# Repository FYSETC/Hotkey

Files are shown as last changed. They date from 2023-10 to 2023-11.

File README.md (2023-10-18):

# Hotkey

## Introduction
Elevate your 3D printing experience with our latest innovation, the HotKey Macro Buttons designed exclusively for the discerning 3D printing enthusiast.

**Key Features:**
- Dedicated MCU: Built on the robust and reliable RP2040 platform, our HotKey system guarantees a seamless integration and flawless performance.
- 12 Linear Red Switched Macro Buttons: Customize your 3D printer like never before. With 12 programmable macro buttons, execute your frequently used commands with a single press. Whether you’re toggling between settings, setting up a new print, or any other task, speed and convenience are at your fingertips.
- Designed with Voron in Mind: While our HotKey Macro Buttons can enhance any 3D printing setup, they were meticulously designed with the Voron Trident and Voron 2.4 models as the primary inspiration. This ensures an impeccable fit and intuitive usage for Voron users.
- Seamless Integration: Add these buttons to your printer's skirt without any hassle. Our design philosophy prioritizes both aesthetics and functionality, ensuring your 3D printer not only gets a boost in efficiency but also looks sleeker.

## Firmware
### Katapult (Formally CAN Boot)
Katapult is used to allow easy upgrading of your formware down the line, and is not just soley for CAN based devices. 
#### Setup Katapult
If you already have Katapult installed, you can skip this step. 

1. Connect to your Klipper host computer via ssh.
2. Clone the Katapult firmware to your Klipper Host
```bash
cd ~/
git clone https://github.com/Arksine/katapult
```
3. Within either Fluidd or Mainsail UI, Edit your Moonraker.conf and add the following at the bottom to allow Moonraker to manage your Katapult updates. 
```yaml
[update_manager Katapult]
type: git_repo
path: ~/katapult
origin: https://github.com/Arksine/katapult.git
is_system_service: False
```
#### Compile Katapult Firmware
1. Navigate into the Katapult Directory
```bash
cd ~/katapult
```
2. Run make clean 
```bash
make clean KCONFIG_CONFIG=config.hotkey
```
3. Open menuconfig 
```bash
make menuconfig KCONFIG_CONFIG=config.hotkey
```
4. Set the following settings
    - Micro-controller Architecture (Raspberry Pi RP2040)
    - Flash Chip (W25Q080 with CLKDIV 2)
    - Build Katapult deployment application (Do not build)
    - Communication interface (USB)
    - () GPIO pins to set on bootloader entry
    - [*] Support bootloader entry on rapid double clip of reset button
    - [_] Enable bootloader entry on button (or gpio) state
    - [_] Enable Status LED
  


5. Quit and save the configuration
6. Run the make command to compile the firmware
```bash
   make KCONFIG_CONFIG=config.hotkey -j4
```
7. You should now have a katapult.uf2 file at ~/katapult/out/

#### Burn Katapult Firmware to the Hotkey Pad
1. Use a USB-C data cable to connect the Hotkey Pad board to the klipper host.
2. Press the boot button while inserting the USB Cable to put the Hotkey Pad into boot mode.
3. Run lsusb to see if the connection is successful.
```bash
  lsusb
```


You should see a device with the ID `2e8a:0003 Raspberry Pi RP2 Boot`, if that doesn't show, please start at step 1 again. 

4. Flash the Hotkey Pad
```bash
sudo make KCONFIG_CONFIG=config.hotkey flash FLASH_DEVICE=2e8a:0003
```
- You will be prompted to enter your password.
- This will flash the Katapult bootloader image and restart the Hotkey Pad
5. Once complete, reboot your host computer and move onto flashing Klipper

### Klipper

#### Compile Klipper firmware for the Hotkey Pad
1. Connect to your Klipper host computer via ssh. 
2. cd to the Klipper directory 
```bash
cd ~/klipper
```
3. Run make clean 
```bash
make clean KCONFIG_CONFIG=config.hotkey
```
4. Open menuconfig 
```bash
make menuconfig KCONFIG_CONFIG=config.hotkey
```
5. Set the following settings
    - [*] Enable extra low-level configuration options
    - Micro-controller Architecture (Raspberry Pi RP2040)
    - Bootloader offset (16KiB bootloader)
    - Communication interface (USB)
    - ( ) GPIO pins to set at micro-controller startup (NEW)


6. Quit (press q) and save the configuration
7. Run Make to compile the firmware
```bash
make KCONFIG_CONFIG=config.hotkey -j4
```
#### Flash Klipper USB firmware with Katapult over USB
1. Find the Serial ID (hint - it will likely say rp2040 in the name. If you have multiple rp2040 based devices, check your printer.cfg and see which ones you are already using).
```bash
ls /dev/serial/by-id
```


2. Copy the ID containing ‘rp2040’ and make a note of it for use in your printer.cfg.
3. Run the make flash command to flash the firmware
```bash
make KCONFIG_CONFIG=config.hotkey flash FLASH_DEVICE= {Your serial ID here }
```
   **Example**
```bash
make KCONFIG_CONFIG=config.hotkey flash FLASH_DEVICE=/dev/serial/by-id/usb-katapult_rp2040_E6625C4893378533-if00
```


 4. Your Hotkey Pad should now have Klipper Firmware installed and be ready to use. You can check it's worked by running another
```bash
ls /dev/serial/by-id
```

## Configuration 

### How to use all this stuff:
1.  Copy this .cfg file into your Klipper config directory and then add `[include Hotkey.cfg]` to the top of your printer.cfg in order to register the MCU, LEDs and macros with Klipper.
2.  If you installed the Stealthburner as well and want to get the "STATUS_ERROR" state transmitted to the hotkey button PCB, you have to replace the "STATUS_ERROR" Macro in your stealthburner_leds.cfg with this:
```bash
[gcode_macro status_error]
gcode:
    STATUS_ERROR_HOTKEY
    _set_sb_leds_by_name leds="logo" color="error" transmit=0
    _set_sb_leds_by_name leds="nozzle" color="error" transmit=1
```
3.  Connect the PCB via USB to your RaspberryPi and SSH to your Pi
4.  Get the Serial ID of the PCB with "ls /dev/serial/by-id/*". Usualy it´s like usb-Klipper_rp2040_xxx
5.  Replace the serial under the [mcu hotkey] section with your id
6.  Save your config and restart Klipper.

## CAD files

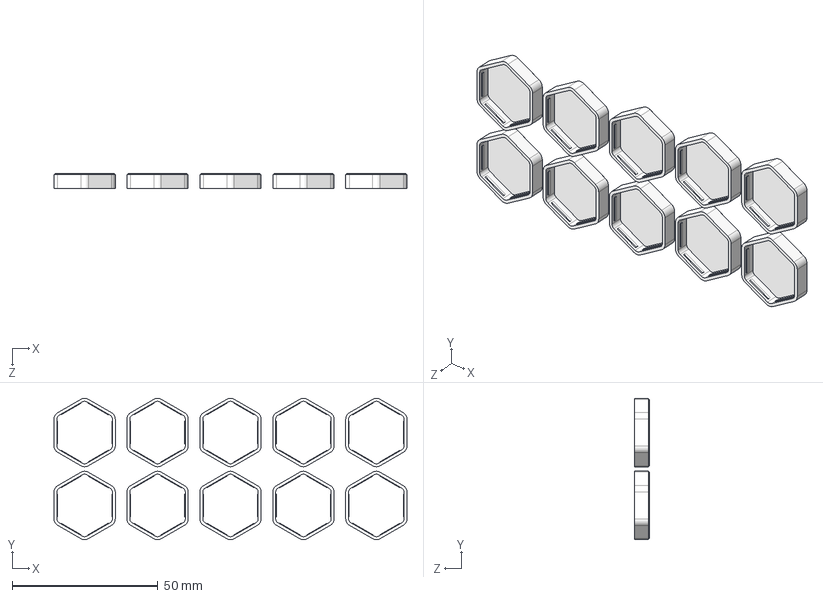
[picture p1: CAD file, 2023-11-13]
Models and dimensions/Button_Caps/KBB.STEP
121.0 x 48.5 x 5.10 mm

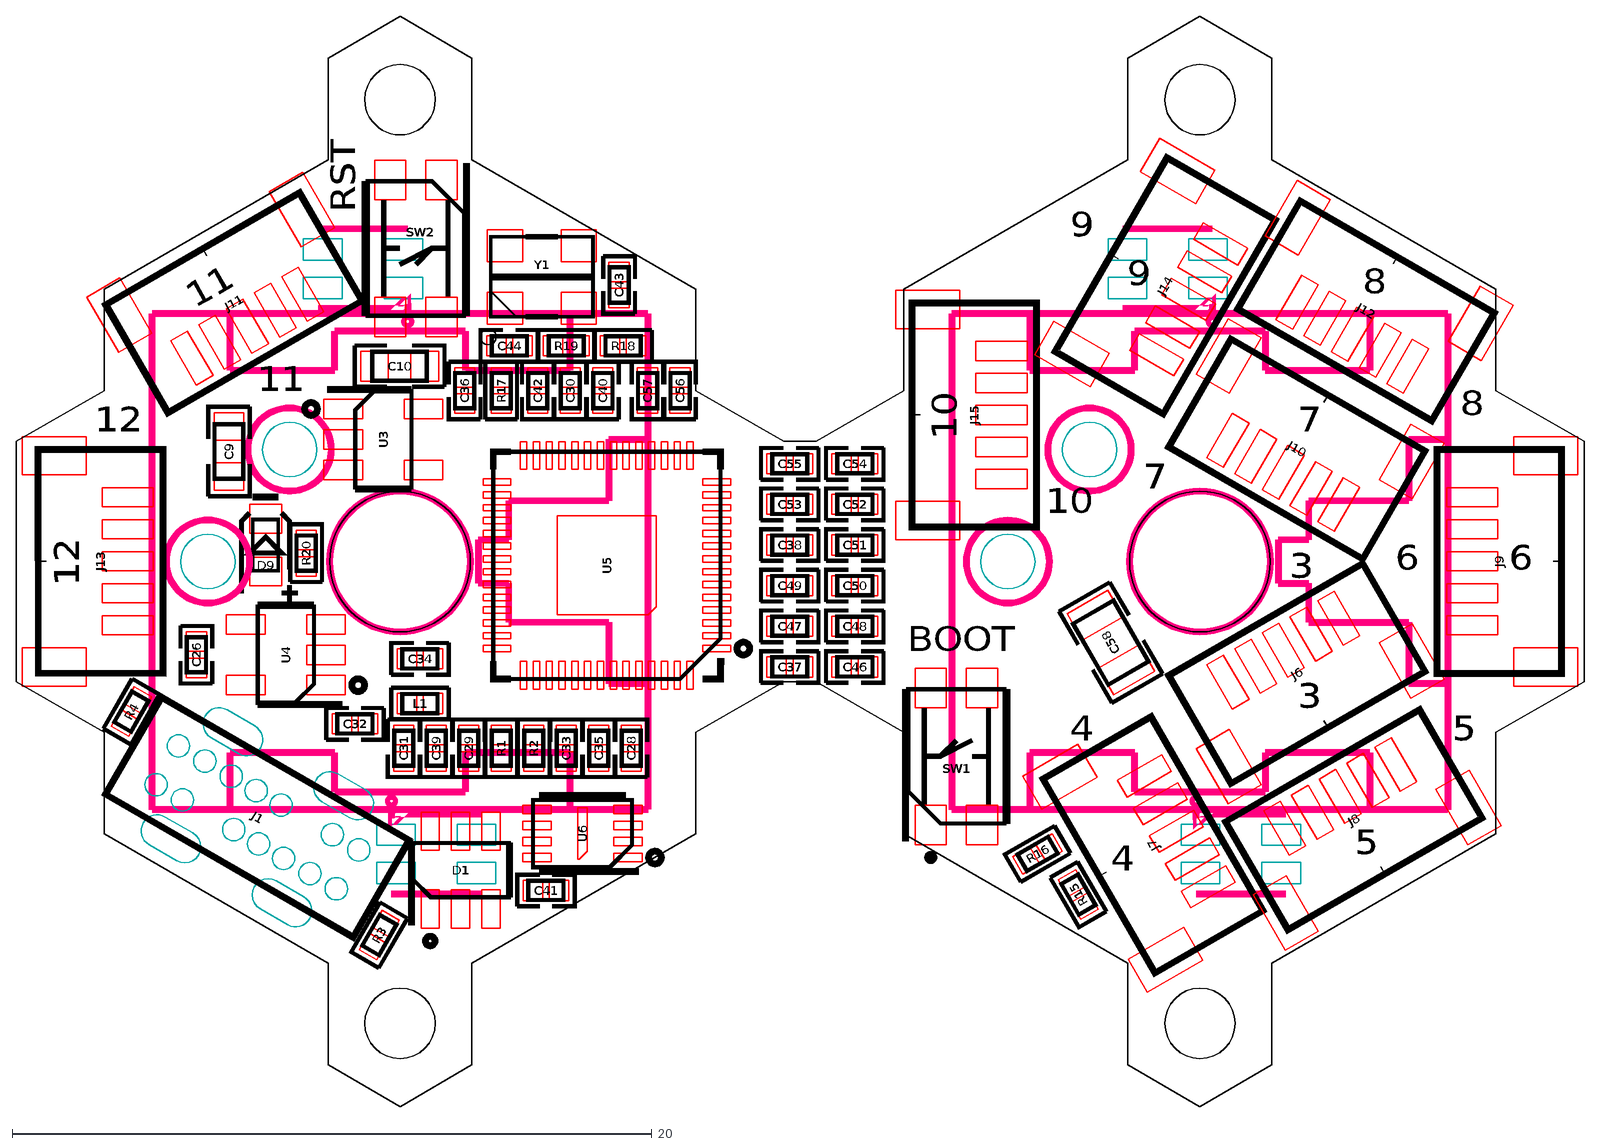
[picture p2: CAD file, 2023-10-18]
Models and dimensions/SKIRT_BUTTON_A2_CAD.dxf
D9
J1
C58
U6
J15
J14
J13
J12
J11
J10
J6
J7
J8
J9
U5
SW2
SW1
C10
C9
R20
L1
R18
R19
R4
R3
R16
R17
R15
R2
R1
C57
C56
C55
C54
C53
C52
C51
C50
C49
C48
C47
C46
C37
C42
C41
C40
C39
C38
C36
C43
C35
C32
C33
C34
C44
C31
C26
C30
C29
C28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

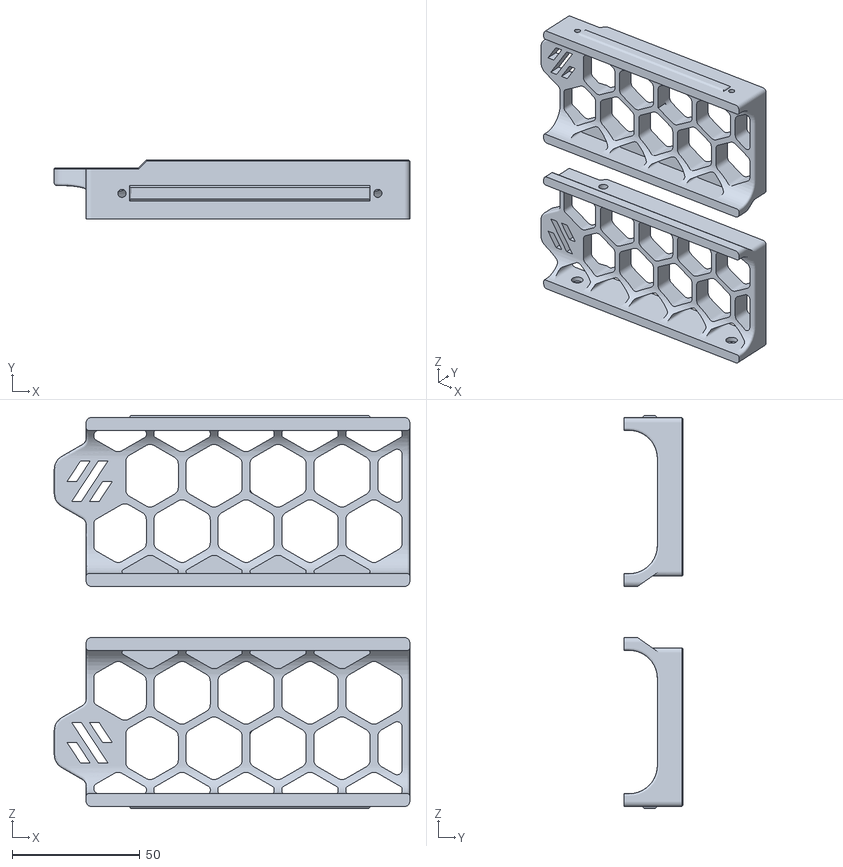
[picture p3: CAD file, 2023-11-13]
Models and dimensions/STL/Skirt_300_Trident_Button_PCB.STL
139.0 x 23.0 x 153.6

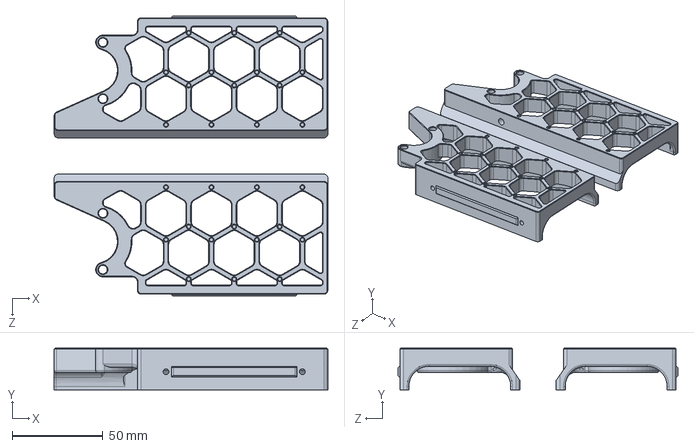
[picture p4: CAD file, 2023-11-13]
Models and dimensions/V2.4/350_v2.4_button_PCB.step.SLDPRT
150.5 x 23.0 x 154.0 mm

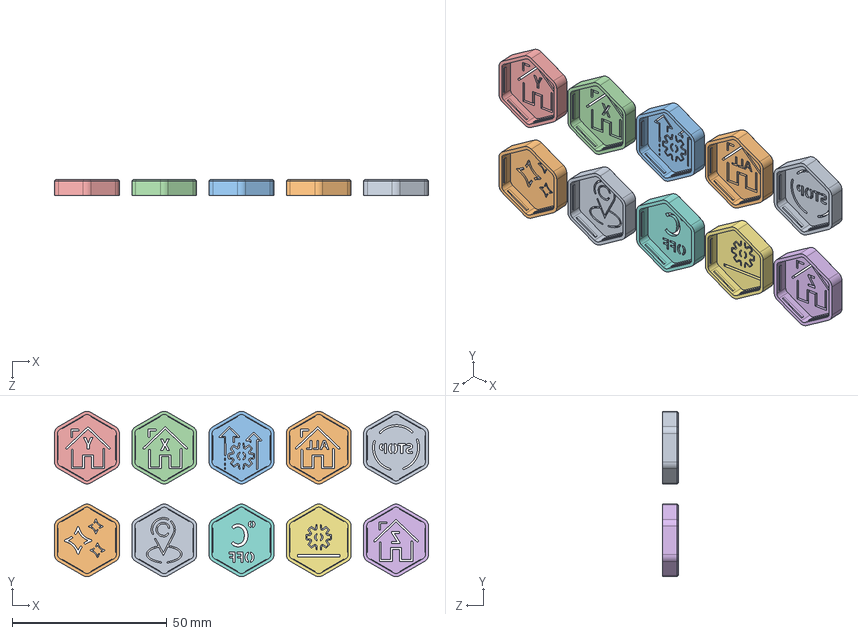
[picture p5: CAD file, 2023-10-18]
Models and dimensions/Button_Caps/BD.STEP
121.0 x 53.5 x 5.10 mm

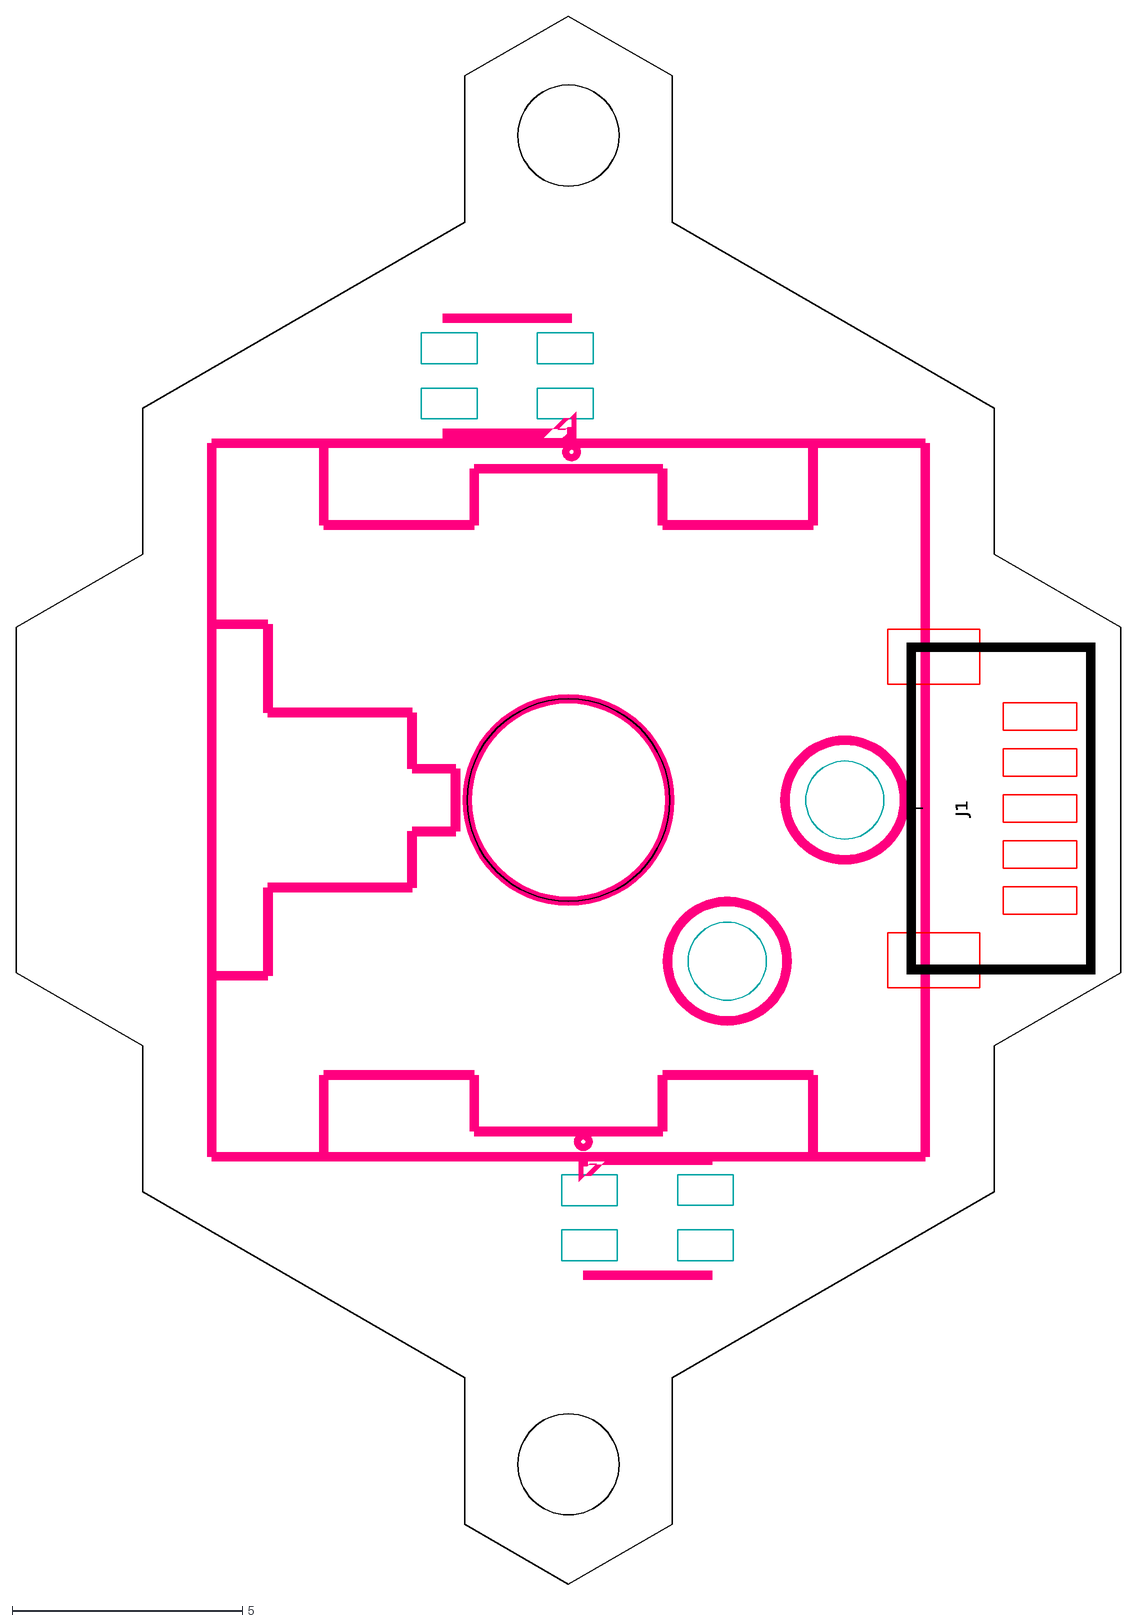
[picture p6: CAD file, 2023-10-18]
Models and dimensions/SKIRT_BUTTON_A1_CAD.dxf
J1

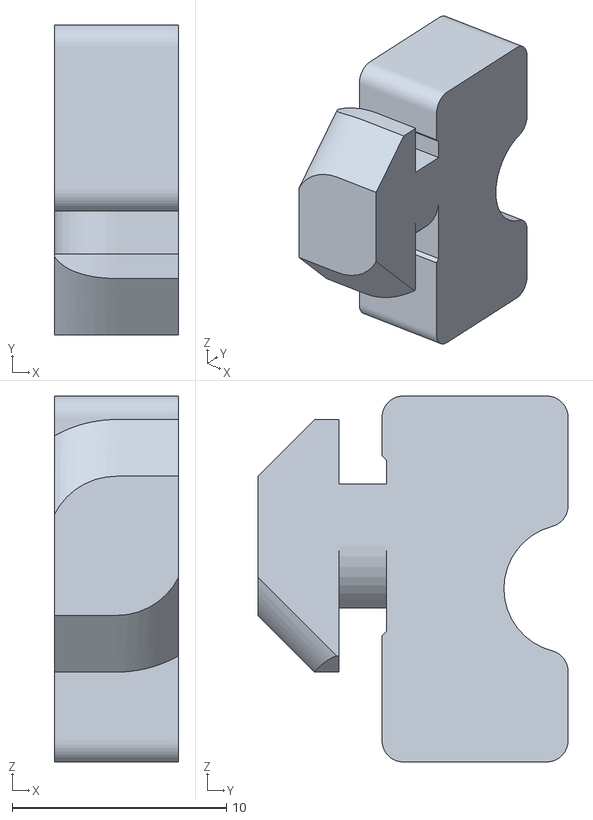
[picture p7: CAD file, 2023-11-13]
Models and dimensions/STL/Deck Support.STL
5.80 x 14.5 x 17.1

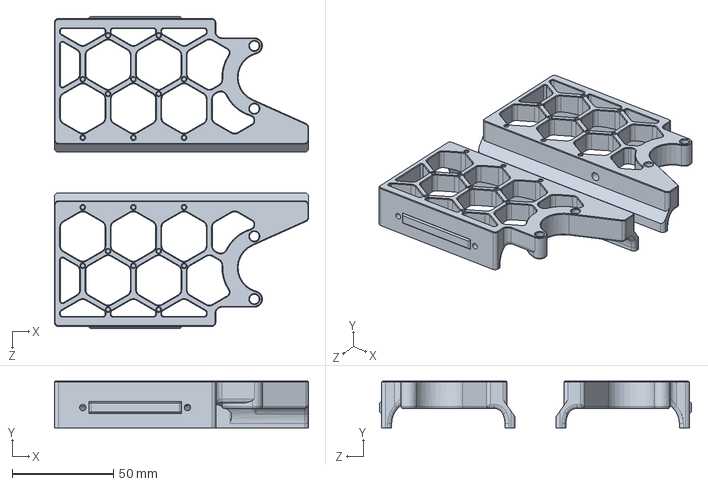
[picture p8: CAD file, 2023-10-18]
Models and dimensions/V2.4/300_v2.4_button_PCB.step.SLDPRT
125.5 x 23.0 x 154.0 mm

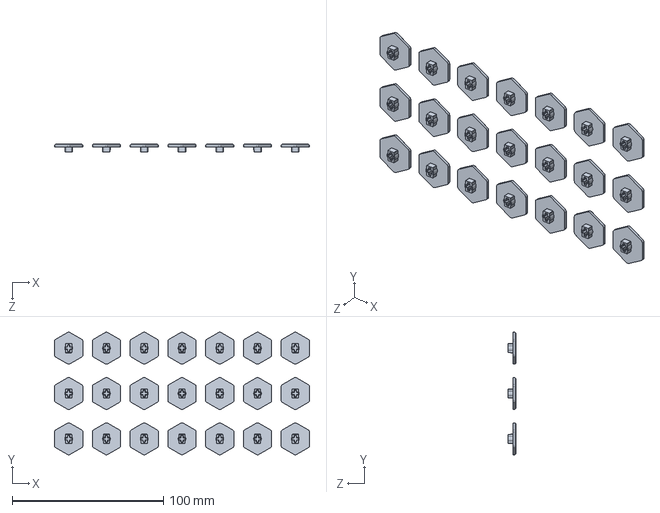
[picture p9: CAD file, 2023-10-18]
Models and dimensions/Button_Caps/CSa.SLDPRT
168.8 x 81.3 x 5.00 mm

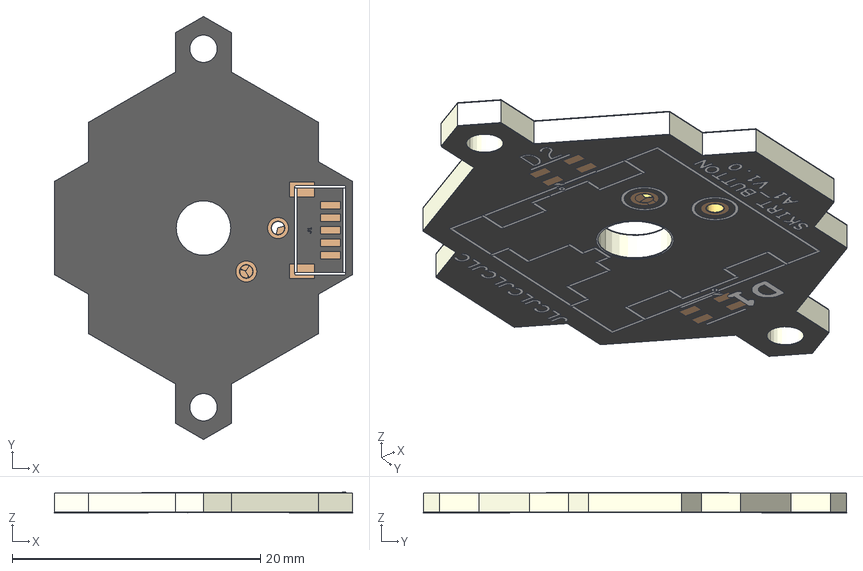
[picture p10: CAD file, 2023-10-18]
Models and dimensions/SKIRT_BUTTON_A1_3D.stp
24.0 x 34.1 x 1.65 mm
DIN x 2
DOUT x 2
MECHANICAL PIN x 2
VDD x 2
VSS x 2
SILKSCREEN_TOP
PASTEMASK_TOP
SOLDERMASK_TOP
TOP
Dielectric
BOTTOM
SOLDERMASK_BOTTOM
PASTEMASK_BOTTOM
SILKSCREEN_BOTTOM
Via x 4

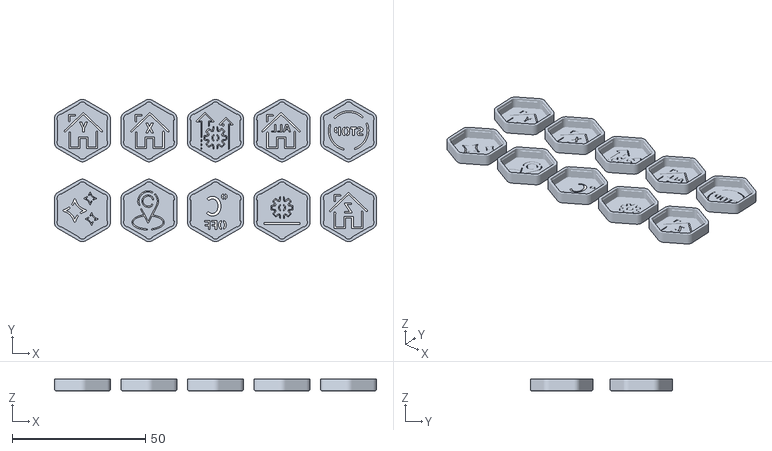
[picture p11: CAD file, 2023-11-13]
Models and dimensions/STL/BD.STL
121.0 x 53.5 x 4.50

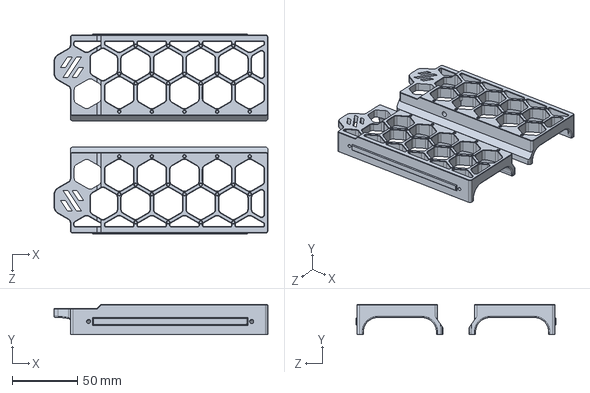
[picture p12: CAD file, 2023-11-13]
Models and dimensions/Trident-Switchwire/Skirt_350_Trident_Button_PCB.step.SLDPRT
164.0 x 23.0 x 153.6 mm

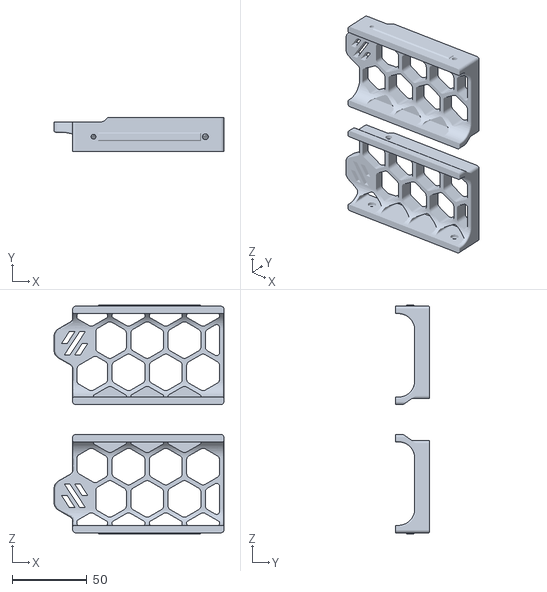
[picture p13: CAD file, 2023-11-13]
Models and dimensions/STL/Skirt_250_Trident_Button_PCB.STL
114.0 x 23.0 x 153.6

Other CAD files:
Models and dimensions/Trident-Switchwire/Skirt_300_Trident_Button_PCB.step.SLDPRT
Models and dimensions/Trident-Switchwire/Deck Support.SLDPRT
Models and dimensions/V2.4/300_v2.4_button_PCB.STEP
Models and dimensions/Button_Caps/ANJBB.STEP
Models and dimensions/Trident-Switchwire/Skirt_250_Trident_Button_PCB.step.SLDPRT
Models and dimensions/Button_Caps/ANJBB.SLDPRT
Models and dimensions/Button_Caps/BD.SLDPRT
Models and dimensions/Button_Caps/CSa.STL
Models and dimensions/Button_Caps/KBB.SLDPRT
Models and dimensions/STL/250_v2.4_button_PCB 0527.STL
Models and dimensions/STL/300_v2.4_button_PCB.STL
Models and dimensions/STL/350_v2.4_button_PCB.STL
Models and dimensions/STL/CSa.STL
Models and dimensions/STL/Skirt_300_Trident_Button_PCB-2.STL
Models and dimensions/STL/Skirt_350_Trident_Button_PCB.STL
Models and dimensions/STL/v2.0_skirt__300_button_PCB.STL
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

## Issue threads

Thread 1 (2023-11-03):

Stock clear button caps too tight

zcohenld, 2023-11-03:
I printed the STL parts for my Voron 2.4 and the clear button caps are too big/tight on the area that goes on the switch. It makes it so when you push the button it sticks down and doesn't come back up.

C00lH4nds, 2024-01-03:
Same here. I had to file down the part of the button caps that go into the switch. Also the STL has too many button caps, there should be only 12.

numindast, 2024-02-24:
I found that when I inspected the bottom of the CSa parts, there's a particular orientation that works better. Rotate the part 90 degrees and it should fit better. May have to tinker with scaling the part up a tiny bit (and scaling the cap up equally if not a little bit more).

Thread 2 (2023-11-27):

Burn katapult firmware: No rp2040 in BOOTSEL mode was found

stevendejongnl, 2023-11-27:
When I try to write the firmware to the hotkey pad I get an error.
`~/katapult$ sudo make KCONFIG_CONFIG=config.hotkey flash FLASH_DEVICE=2e8a:000a --debug
GNU Make 4.3
Built for aarch64-unknown-linux-gnu
Copyright (C) 1988-2020 Free Software Foundation, Inc.
License GPLv3+: GNU GPL version 3 or later <http://gnu.org/licenses/gpl.html>
This is free software: you are free to change and redistribute it.
There is NO WARRANTY, to the extent permitted by law.
Reading makefiles...
Updating makefiles....
Updating goal targets....
 File 'flash' does not exist.
Must remake target 'flash'.
  Flashing out/katapult.uf2
Loaded UF2 image with 21 pages
No rp2040 in BOOTSEL mode was found
Successfully remade target file 'flash'.`

The device identifies itself as `Bus 001 Device 009: ID 2e8a:000a Raspberry Pi Pico` instead of `Raspberry Pi RP2 Boot`.

theminjus, 2023-12-06:
Having similar issue  , i have burn new loader , but klipper doesnt want to boot
also mine is named as usb-Raspberry_Pi_Pico_E6625C4893418833-if00

vjeko2404, 2023-12-22:
Did you manage to solve the issue? Having similar problems when I try to reflash klipper firmware.
Its also usb-Raspberry_Pi_Pico_*********************

llambion72, 2023-12-28:
I've started to install this hot key and i'va the same error. I can`t enable it.

vjeko2404, 2023-12-28:
I had the same issues but managed to get it working. Basically are the steps in readme correct and need to be execately followed.
I missed one step during Katapult install and had above mentioned error.
If your device identifies as  usb-Raspberry_Pi_Pico_**************** then the Katapult installation didn't worked well.
Also, pay attention to "_Press the boot button while inserting the USB Cable to put the Hotkey Pad into boot mode._"

llambion72, 2023-12-30:
I've changed usb cable and now It works OK.

PeteUgrin, 2024-01-31:
> I had the same issues but managed to get it working. Basically are the steps in read me correct and need to be exacatly followed. I missed one step during Katapult install and had above mentioned error. If your device identifies as usb-Raspberry_Pi_Pico_**************** then the Katapult installation didn't worked well. Also, pay attention to "_Press the boot button while inserting the USB Cable to put the Hotkey Pad into boot mode._"

Done it properly. Got the Katapult address and see the new mcu in the ssh. The problem starts when I include the hotkey.cfg. The printer just w8 to connect to the new mcu. When I comment out the include, the printer works fine. Got klipper 0.11.0. Might that be the problem?

Changed the cable. Did the installation step by step. Still wonder.

CBoismenu, 2024-02-03:
Same problem for me it shows up has a Raspberry Pi Pico.

PeteUgrin, 2024-02-03:
Got it! Problem solved! There are two buttons! One is boot and one is reset. Reset is bigger and better accessible. Boot button is smaller and way more hidden. Just do press the right one. Than everything works perfectly.

Also if you have klipper-led_effects installed, it will collide with the buttons LED setup in the hotkey cfg file. You will have to set up the hotkey LED effects via the klipper-led_effects.

https://github.com/julianschill/klipper-led_effect

stefi01, 2024-02-24:
thanks. there are two buttons, hard to find the button needed, it is around 5 oclock from the main ic and next to a jst plug but it worked.

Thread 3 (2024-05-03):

LED not lighting up

xavid85, 2024-05-03:
LED's not lighting up followed all the instructions properly included the hotkey.cfg to the printer.cfg but still nothing, the 2 connected directly to the board lights up but the rest never turns on

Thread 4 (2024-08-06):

Flashing Klipper

Dan-1290, 2024-08-06:
To flash klipper once katapult is installed the guide says to use a 16kb bootloader but that unfortunately doesn't work. The workaround for this is to use no bootloader then it works fine as it should. (in my case anyways your mileage might vary)

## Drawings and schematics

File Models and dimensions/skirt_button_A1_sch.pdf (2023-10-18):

5

4

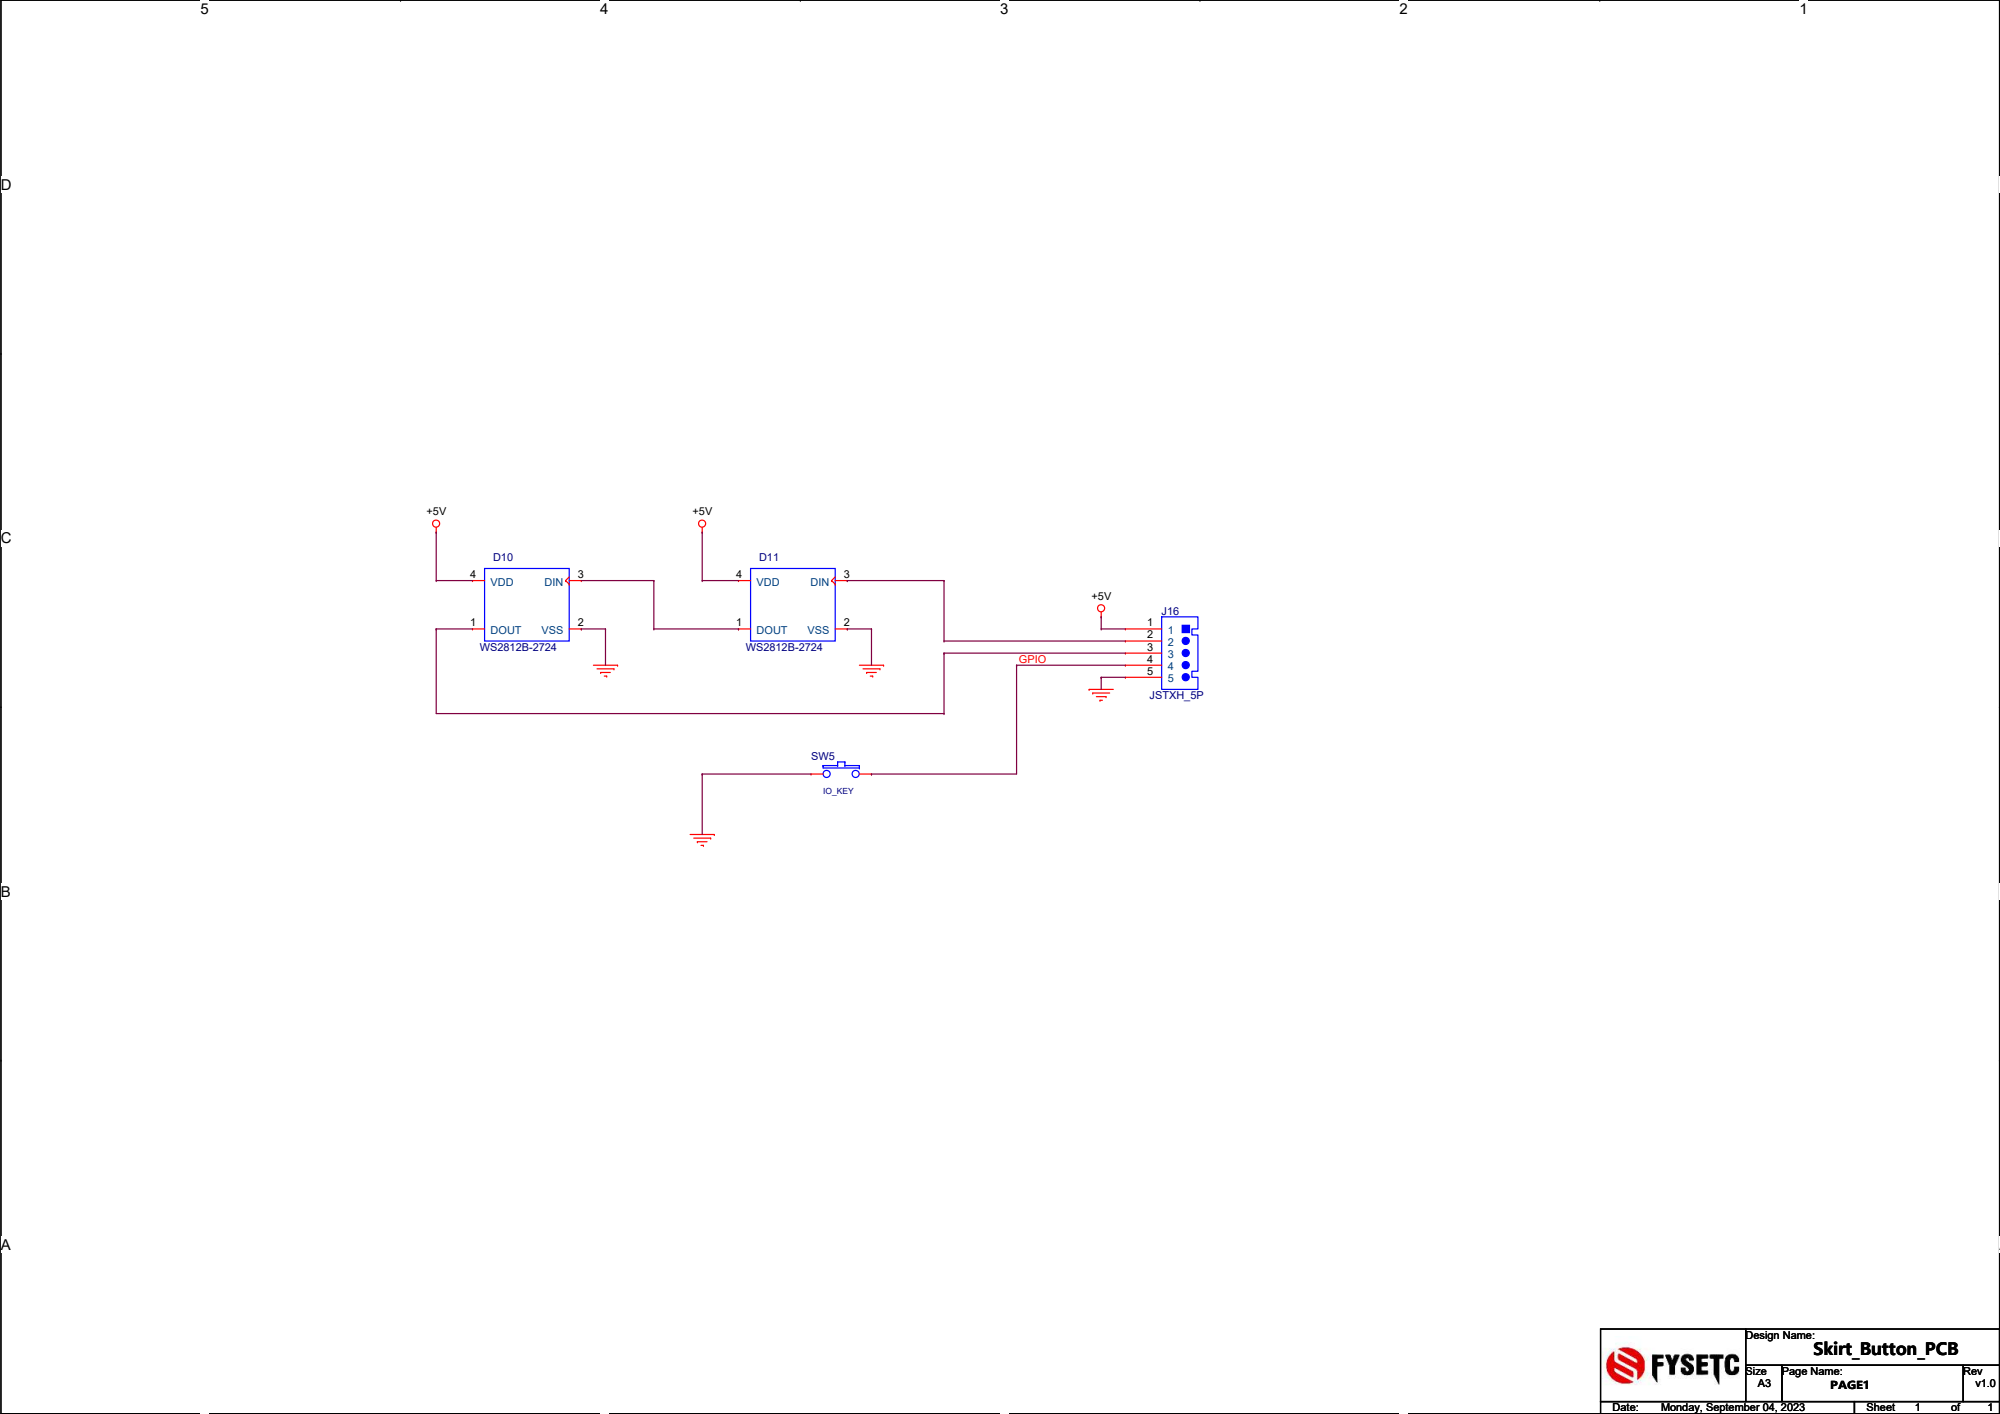
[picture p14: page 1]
Design Name:; Size; Page Name:; Rev; Date:; Sheet; Skirt_Button_PCB; Monday, September 04, 2023; PAGE1; IO_KEY; VDD 4; DOUT 1; VSS; DIN; JSTXH_5P; GPIO

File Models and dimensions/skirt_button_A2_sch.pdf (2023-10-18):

5

4

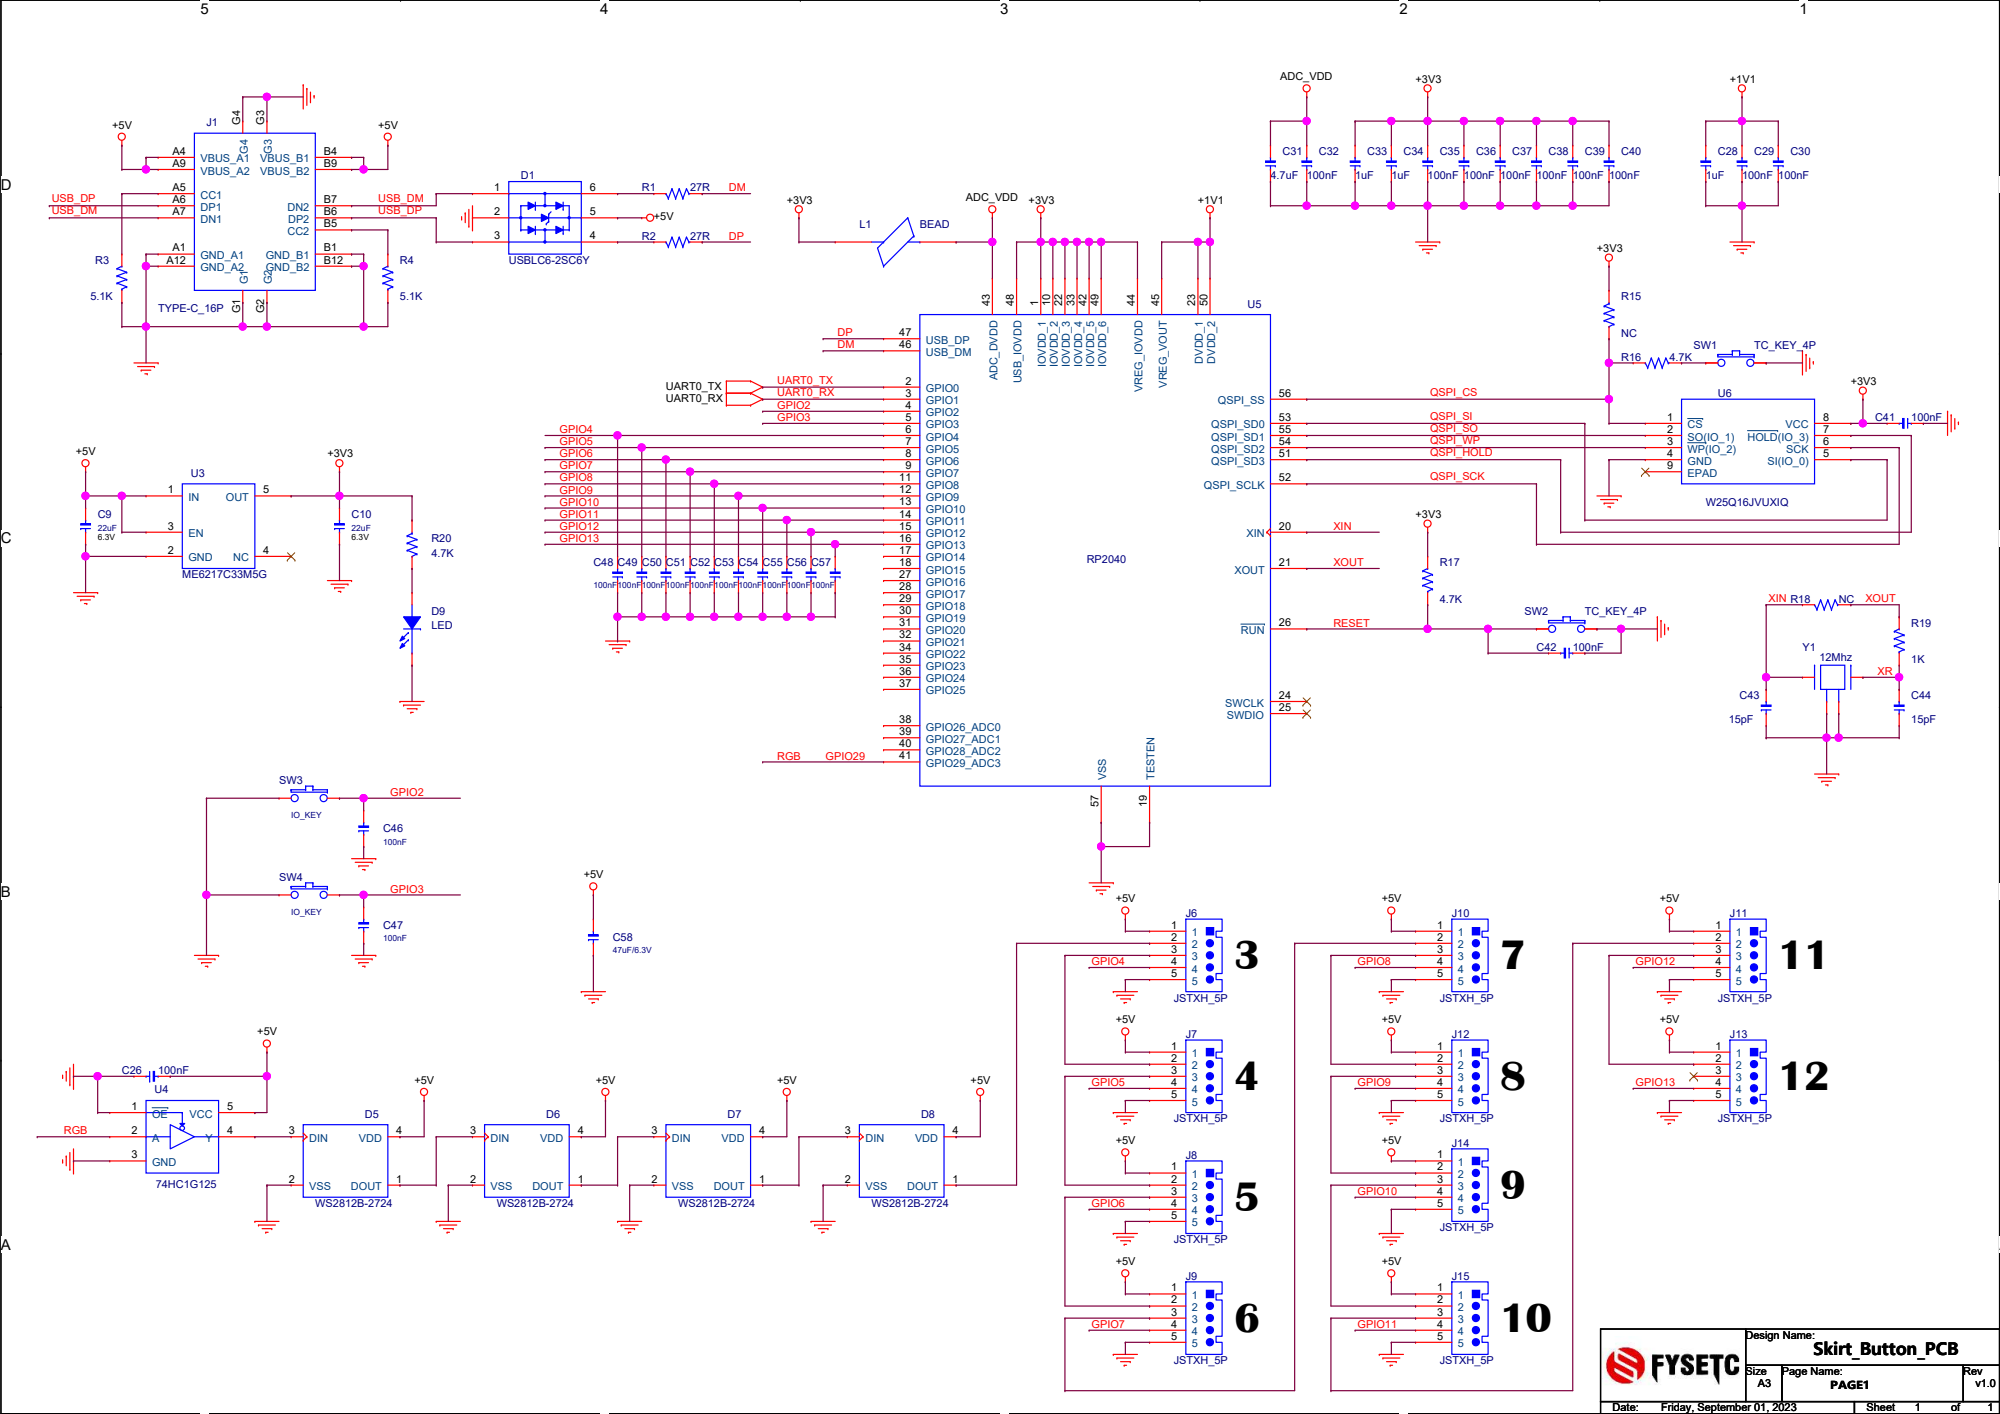
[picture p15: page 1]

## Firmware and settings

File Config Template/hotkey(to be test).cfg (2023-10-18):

#####################################
#           INSTRUCTIONS            #
#####################################
# 
# The Voron Hotkey board commes pre-flashed. So you don´t have to compile and upload any firmware to the board.
#
# How to use all this stuff:
#
#     1.  Copy this .cfg file into your Klipper config directory and then add [include Hotkey.cfg]
#         to the top of your printer.cfg in order to register the MCU, LEDs and macros with Klipper.
#
#     2.  If you installed the Stealthburner as well and want to get the "STATUS_ERROR" state transmitted to the hotkey button PCB,
#         you have to replace the "STATUS_ERROR" Macro in your stealthburner_leds.cfg with this without the "#":
#
#[gcode_macro status_error]
#gcode:
#    STATUS_ERROR_HOTKEY
#    _set_sb_leds_by_name leds="logo" color="error" transmit=0
#    _set_sb_leds_by_name leds="nozzle" color="error" transmit=1
#
#     3.  Connect the PCB via USB to your RaspberryPi and SSH to your Pi
#
#     4.  Get the Serial ID of the PCB with "ls /dev/serial/by-id/*". Usualy it´s like usb-Klipper_rp2040_xxx
#
#     5.  Replace the serial under the [mcu hotkey] section with your id
#
#     6.  Save your config and restart Klipper.
#

#####################################
#           User Config             #
#####################################



[mcu hotkey]
serial: /dev/serial/by-id/usb-Klipper_rp2040_E66058919F365C30-if00 
restart_method: command

[idle_timeout]
gcode:
  status_standby_hotkey
timeout: 1800

#####################################
#           Macro Config            #
#####################################
#
# All of the buttons are configured with macros.
# Some of them are self-made, like the PREHEAT and CLEAN_NOZZLE and will not work at the beginning.
# In order to get them work, you have to define them in your config.
# Please refer to https://www.klipper3d.org/Config_Reference.html?h=macro#g-code-macros-and-events
#

[gcode_macro _BUTTON_B1]
# EMERGENCY STOP
# Home Z
gcode:
  _status_button_busy BUTTON=1
  #M112
  G28 Z
  _status_button_ready BUTTON=1

[gcode_macro _BUTTON_B2]
# Go to service position
gcode:
  _status_button_busy BUTTON=2
  G0 X175 Y50 Z50 F18000
  _status_button_ready BUTTON=2

[gcode_macro _BUTTON_B3]
# Clean Nozzle
gcode:
  _status_button_busy BUTTON=3
  CLEAN_NOZZLE
  _status_button_ready BUTTON=3

[gcode_macro _BUTTON_B4]
#Homing All
gcode:
  _status_button_busy BUTTON=4
  G28
  _status_button_ready BUTTON=4

[gcode_macro _BUTTON_B5]
#Preheat
gcode:
  _status_button_busy BUTTON=5
  PREHEAT
  _status_button_ready BUTTON=5

[gcode_macro _BUTTON_B6]
#Unload Filament
gcode:
  _status_button_busy BUTTON=6
  UNLOAD_FILAMENT
  _status_button_ready BUTTON=6

[gcode_macro _BUTTON_B7]
#Load Filament
gcode:
  _status_button_busy BUTTON=7
  LOAD_FILAMENT LENGTH=10 SPEED=10 EXTRUDER=extruder MINIMUM=210 BEEPS=10                 
  _status_button_ready BUTTON=7 


[gcode_macro _BUTTON_B8]
#Cancel Printing
gcode:
  _status_button_busy BUTTON=8
  CANCEL_PRINT
  _status_button_ready BUTTON=8


[gcode_macro _BUTTON_B9]
#Rause Printing
gcode:
  _status_button_busy BUTTON=9
  PAUSE
  _status_button_ready BUTTON=9

[gcode_macro _BUTTON_B10]
#Resume Printing
gcode:
  _status_button_busy BUTTON=10
  RESUME
  _status_button_ready BUTTON=10

[gcode_macro _BUTTON_B11]
#Home X
gcode:
  _status_button_busy BUTTON=11
  G28 X 
  _status_button_ready BUTTON=11


[gcode_macro _BUTTON_B12]
#Home Y
gcode:
  _status_button_busy BUTTON=12
  G28 Y 
  _status_button_ready BUTTON=12





# Config for the hotkey button LEDs
[neopixel hotkey_leds]
pin: hotkey: gpio29
chain_count: 24
color_order: GRB
initial_RED: 0.5
initial_GREEN: 0.5
initial_BLUE: 0.5

# Settings for the Buttons
[gcode_button b1]
pin: ^!hotkey: gpio2
press_gcode: _BUTTON_B1

[gcode_button b2]
pin: ^!hotkey: gpio3
press_gcode: _BUTTON_B2

[gcode_button b3]
pin: ^!hotkey: gpio4
press_gcode: _BUTTON_B3

[gcode_button b4]
pin: ^!hotkey: gpio5
press_gcode: _BUTTON_B4

[gcode_button b5]
pin: ^!hotkey: gpio6
press_gcode: _BUTTON_B5

[gcode_button b6]
pin: ^!hotkey: gpio7
press_gcode: _BUTTON_B6

[gcode_button b7]
pin: ^!hotkey: gpio8
press_gcode: _BUTTON_B7

[gcode_button b8]
pin: ^!hotkey: gpio9
press_gcode: _BUTTON_B8

[gcode_button b9]
pin: ^!hotkey: gpio10
press_gcode: _BUTTON_B9

[gcode_button b10]
pin: ^!hotkey: gpio11
press_gcode: _BUTTON_B10

[gcode_button b11]
pin: ^!hotkey: gpio12
press_gcode: _BUTTON_B11

[gcode_button b12]
pin: ^!hotkey: gpio13
press_gcode: _BUTTON_B12



#####################################
#           Color Config            #
#####################################

[gcode_macro _hotkey_vars]
# User settings for the hotkey Button status leds. You can change the status colors and led
# configurations for all 12 buttons here.
variable_colors: {
        'b1': { # Colors for b1 states
            'busy': {'r': 0.1, 'g': 0.1, 'b': 0.0,},
            'standby': {'r': 0.1, 'g': 0.0, 'b': 0.1,},
            'ready': {'r': 0.0, 'g': 0.1, 'b': 0.0,},
            'error': {'r': 0.2, 'g': 0.0, 'b': 0.0},
            'printing': {'r': 0.2, 'g': 0.0, 'b': 0.0},
        },
        'b2': { # Colors for b2 states
            'busy': {'r': 0.1, 'g': 0.1, 'b': 0.0,},
            'standby': {'r': 0.1, 'g': 0.0, 'b': 0.1,},
            'ready': {'r': 0.0, 'g': 0.1, 'b': 0.0,},
            'error': {'r': 0.2, 'g': 0.0, 'b': 0.0},
            'printing': {'r': 0.0, 'g': 0.0, 'b': 0.0},
        },
        'b3': { # Colors for b3 states
            'busy': {'r': 0.1, 'g': 0.1, 'b': 0.0,},
            'standby': {'r': 0.1, 'g': 0.0, 'b': 0.1,},
            'ready': {'r': 0.0, 'g': 0.1, 'b': 0.0,},
            'error': {'r': 0.2, 'g': 0.0, 'b': 0.0},
            'printing': {'r': 0.0, 'g': 0.0, 'b': 0.0},
        },
        'b4': { # Colors for b4 states
            'busy': {'r': 0.1, 'g': 0.1, 'b': 0.0,},
            'standby': {'r': 0.1, 'g': 0.0, 'b': 0.1,},
            'ready': {'r': 0.0, 'g': 0.1, 'b': 0.0,},
            'error': {'r': 0.2, 'g': 0.0, 'b': 0.0},
            'printing': {'r': 0.0, 'g': 0.0, 'b': 0.0},
        },
        'b5': { # Colors for b5 states
            'busy': {'r': 0.1, 'g': 0.1, 'b': 0.0,},
            'standby': {'r': 0.1, 'g': 0.0, 'b': 0.1,},
            'ready': {'r': 0.0, 'g': 0.1, 'b': 0.0,},
            'error': {'r': 0.2, 'g': 0.0, 'b': 0.0},
            'printing': {'r': 0.0, 'g': 0.0, 'b': 0.0},
        },
        'b6': { # Colors for b6 states
            'busy': {'r': 0.1, 'g': 0.1, 'b': 0.0,},
            'standby': {'r': 0.1, 'g': 0.0, 'b': 0.1,},
            'ready': {'r': 0.0, 'g': 0.1, 'b': 0.0,},
            'error': {'r': 0.2, 'g': 0.0, 'b': 0.0},
            'printing': {'r': 0.0, 'g': 0.0, 'b': 0.0},
        },
        'b7': { # Colors for b7 states
            'busy': {'r': 0.1, 'g': 0.1, 'b': 0.0,},
            'standby': {'r': 0.1, 'g': 0.0, 'b': 0.1,},
            'ready': {'r': 0.0, 'g': 0.1, 'b': 0.0,},
            'error': {'r': 0.2, 'g': 0.0, 'b': 0.0},
            'printing': {'r': 0.0, 'g': 0.0, 'b': 0.0},
        },
        'b8': { # Colors for b4 states
            'busy': {'r': 0.1, 'g': 0.1, 'b': 0.0,},
            'standby': {'r': 0.1, 'g': 0.0, 'b': 0.1,},
            'ready': {'r': 0.0, 'g': 0.1, 'b': 0.0,},
            'error': {'r': 0.2, 'g': 0.0, 'b': 0.0},
            'printing': {'r': 0.0, 'g': 0.0, 'b': 0.0},
        },
        'b9': { # Colors for b5 states
            'busy': {'r': 0.1, 'g': 0.1, 'b': 0.0,},
            'standby': {'r': 0.1, 'g': 0.0, 'b': 0.1,},
            'ready': {'r': 0.0, 'g': 0.1, 'b': 0.0,},
            'error': {'r': 0.2, 'g': 0.0, 'b': 0.0},
            'printing': {'r': 0.0, 'g': 0.0, 'b': 0.0},
        },
        'b10': { # Colors for b6 states
            'busy': {'r': 0.1, 'g': 0.1, 'b': 0.0,},
            'standby': {'r': 0.1, 'g': 0.0, 'b': 0.1,},
            'ready': {'r': 0.0, 'g': 0.1, 'b': 0.0,},
            'error': {'r': 0.2, 'g': 0.0, 'b': 0.0},
            'printing': {'r': 0.0, 'g': 0.0, 'b': 0.0},
        },
        'b11': { # Colors for b7 states
            'busy': {'r': 0.1, 'g': 0.1, 'b': 0.0,},
            'standby': {'r': 0.1, 'g': 0.0, 'b': 0.1,},
            'ready': {'r': 0.0, 'g': 0.1, 'b': 0.0,},
            'error': {'r': 0.2, 'g': 0.0, 'b': 0.0},
            'printing': {'r': 0.0, 'g': 0.0, 'b': 0.0},
        },
        'b12': { # Colors for b7 states
            'busy': {'r': 0.1, 'g': 0.1, 'b': 0.0,},
            'standby': {'r': 0.1, 'g': 0.0, 'b': 0.1,},
            'ready': {'r': 0.0, 'g': 0.1, 'b': 0.0,},
            'error': {'r': 0.2, 'g': 0.0, 'b': 0.0},
            'printing': {'r': 0.0, 'g': 0.0, 'b': 0.0},  
        },
    }
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

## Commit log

2023-10-18 Update hotkey(to be test).cfg
    [hotkey(to be test).cfg]
2023-10-18 Initial Flashing Guide
    Initial Flashing Guide -
    Flashing Katapult & Klipper
2023-11-13 update 3D files
    [350_v2.4_button_PCB.step.SLDPRT, BD.SLDPRT, BD.STL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]
